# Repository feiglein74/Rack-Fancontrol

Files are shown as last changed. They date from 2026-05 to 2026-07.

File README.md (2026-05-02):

# Rack-Fancontrol

Eine bewusst überdimensionierte Lüftersteuerung für ein Mini-Serverrack.

Ein **ESP32-S3** läuft mit ESPHome-Firmware, holt sich live die CPU-
und SFP+-DDM-Temperaturen eines **MikroTik CRS305** per SNMP, schickt
sie durch einen PID-Regler und steuert damit zwei 12-V-Lüfter mit
einer gestaffelten Kühlkurve: Der leise 4-Pin-Lüfter macht die
Grundlast, der laute 2-Pin-Lüfter wird erst zugeschaltet, wenn ein
Lüfter allein nicht mehr reicht.

Ziel: Rack kühl halten, Büro leise halten — und dabei etwas zum
Drucken, Löten und Tunen haben.

---

## Hardware

| Bauteil | Funktion |
|---|---|
| ESP32-S3-DevKitC-1 | Hirn. Läuft ESPHome 2026.3.x auf `esp-idf`. |
| 4-Pin-PC-Lüfter (12 V) | Hauptlüfter. PWM @ 25 kHz auf GPIO4, Tacho auf GPIO5. |
| 2-Pin-BLDC-Lüfter (12 V) | Boost-Lüfter. Über 60N03-MOSFET-Modul @ 100 Hz auf GPIO6. |
| INA219 (0,1 Ω Shunt) | Live-Strom-/Leistungsmessung der Lüfterschiene. |
| XW026FR4 Buck Converter | 12 V → 5 V für den ESP. |
| BSS138 Levelshifter | 3,3 V ↔ 5 V auf den PWM-/Tacho-Leitungen für den 4-Pin-Lüfter. |
| 3× WAGO 221-415 | Lötfreie Klemmen für 12 V / 12 V-nach-INA / GND. |

I²C läuft mit **100 kHz** (das billige INA219-Breakout antwortet bei
den 50 kHz Default nicht). Lüfter 2 PWM läuft mit **100 Hz**, weil
2-Pin-BLDC-Lüfter sich bei 25 kHz Versorgungschoppen nicht regeln
lassen — sie schalten dann nur an/aus durch. Bei niedriger PWM-
Frequenz mittelt die Motor-Induktivität die Pulse weg.

## Regelarchitektur

```
MikroTik SNMP (CPU + SFP+1/2 Temperaturen, 60 s Poll, EMA-gefiltert)
                         │
                         ▼
                  rack_max_temp (Template-Maximum)
                         │
                         ▼
                  climate.pid (45 °C Sollwert, ±1,5 °C Totband)
                         │ cool_output (0,0..1,0)
                         ▼
                  Staged-Cooling Template-Output
                ┌────────┴────────┐
                ▼                 ▼
        Lüfter 1 (0..0,5)  Lüfter 2 (0,5..1,0)
        4-Pin LEDC PWM     2-Pin via MOSFET
```

Die `fan.speed`-Entities umschließen zusätzlich jeden LEDC-Output —
wenn `climate.mode = OFF` werden die Lüfter manuell aus Home Assistant
oder dem lokalen Web-UI steuerbar, ohne dass der PID-Regler dazwischen-
funkt.

## Features

- **PID über SNMP** — der Regler arbeitet gegen einen selbst-
  geschriebenen SNMPv2c-GET-Client (`components/snmp_sensor/`,
  ~250 Zeilen C++, ohne externe Library — nur ein ASN.1/BER-Encoder,
  ein Wert-Parser für INTEGER + Gauge32 und ein nicht-blockierender
  UDP-State-Machine).
- **Gestaffelte Kühlung** — ein einzelner PID-Output wird nicht-linear
  auf zwei Lüfter aufgeteilt, damit der Laute aus bleibt, solange es
  geht.
- **Auto-Kalibrierung** — ein Button "Fan 1 kalibrieren" fährt die
  PWM-Pegel 0/25/40/55/70/85/100 % ab und interpoliert die Totzonen-
  Schwelle aus der Tacho-Antwort. Der PID-Output wird anschließend
  auf `[Totzone..100 %]` skaliert, damit der Lüfter nie in seinem
  trägen Bereich hängt.
- **Live-Tuning** — `climate.pid.set_control_parameters` und
  `climate.pid.autotune` sind als Service exponiert; kein Reflash
  nötig.
- **Lokale INA219-Telemetrie** — Strom, Spannung und Leistung der
  Lüfterschiene mit 1 Hz.
- **Home-Assistant-nativ** — Climate-, Fan-, Sensor- und
  Text-Entities über die ESPHome-API; OTA auf Port 3232,
  Web-UI auf Port 80.

## Build & Flash

ESPHome 2026.3.x ist Voraussetzung. WLAN-Zugangsdaten liegen in
`secrets.yaml` (gitignored — selbst anlegen mit `wifi_ssid` /
`wifi_password`).

```bash
esphome config   rack-fancontrol.yaml                   # validieren
esphome compile  rack-fancontrol.yaml                   # bauen
esphome run      --device <ip|serial> rack-fancontrol.yaml
esphome logs     --device <ip> rack-fancontrol.yaml
```

Erstflash über USB-C, danach geht alles per OTA. Innerhalb 60 s
nach einem OTA das Gerät **nicht** stromlos machen — sonst rollt
`safe_mode` das Image als vermeintlicher Boot-Loop wieder zurück.

## Repo-Struktur

```
rack-fancontrol.yaml          ESPHome-Hauptkonfiguration
components/snmp_sensor/       Eigene external_component (SNMPv2c-GET-Client)
enclosure/                    OpenSCAD-Quellen für das 3D-Druck-Gehäuse
CLAUDE.md                     Engineering-Notizen, Pin-Map, Begründungen
```

## Gehäuse (work in progress)

Die Steuerung wandert gerade vom Dupont-Kabel-Dschungel in ein
parametrisches 3D-Druck-Gehäuse, entworfen in **OpenSCAD** für
FDM-Druck.

**Aktueller Stand — Bodenplatte (`enclosure/base_plate.scad`):**

- 160 × 90 × 3 mm abgerundetes Rechteck, mit Lüftungsschlitzen
  unter den warmen Modulen (ESP, MOSFET) für passive Konvektion.
- **Snap-Cradles** für jedes Modul — keine Schrauben. Vier
  gedruckte Federclips pro Modul greifen mit 0,8 mm Lippe über
  die PCB-Kante; die Platinen werden von oben eingeklippst.
- Das ESP-DevKit ist **kopfüber** montiert (Pin-Header oben,
  damit Dupont-Stecker direkt von oben aufgesteckt werden können)
  auf 8 mm Standoffs, damit die WiFi-Antenne und die Unterseiten-
  Bauteile Platz haben.
- WAGO-221-415-Halter nutzen ein Community-STL
  ([Wago 221-415 Connector x 5 Mount](https://www.printables.com/model/321904)
  von *Wiseone*), importiert und im parametrischen Layout neu
  positioniert.
- Alle Modul-Maße sind erst mal Typenwerte; nach dem ersten
  Testdruck werden sie pro echtem Bauteil mit Messschieber
  feingetrimmt.

**Geplant:**

- Wände + Deckel (zum Aufstecken), mit Kabelausgängen auf den
  schmalen Seiten (12 V rein, Lüfteranschlüsse raus, USB-C-
  Wartungsklappe).
- Entweder Rack-Format (10″) als Frontblende oder freistehend —
  je nachdem, ob im LabRax noch ein Slot frei wird.
- Eine kleine Frontaussparung für ein OLED-Statusdisplay liegt
  noch auf dem Tisch.

Die OpenSCAD-Quelle ist absichtlich parameterlastig: Modul tauschen
(anderes INA-Breakout, kleinerer Buck etc.) ist eine Zeile Edit
plus Re-Render.

## Bekannte Eigenheiten

- **Lüfter-2-Brumm.** 100 Hz PWM hört man. Ein 47–100 µF Elko
  parallel zum Lüfter glättet das fast komplett weg — silent
  upgrade, noch nicht eingebaut.
- **MikroTik-Temperaturauflösung.** RouterOS meldet die CPU-
  Temperatur nur in ganzen Grad (die deciDegree-OID-Codierung
  ist kosmetisch). Der EMA-Filter (α=0,4, 60 s Poll) glättet
  die Quantisierungsstufen, damit der D-Term des PID die
  Integer-Sprünge nicht als Schläge sieht.
- **SFP+-DDM.** Modultemperaturen kommen als Gauge32 über SNMP.
  Der Custom-Parser musste auf Tag `0x42` erweitert werden, weil
  die ursprüngliche INTEGER-only-Version NaN zurückgab. Das
  Modul `sfpplus4-uplink` ist aus dem PID-Input ausgenommen —
  dessen DDM-Werte schwanken zu stark.
- **VLAN-Routing nötig.** Der ESP hängt im IoT-VLAN, der MikroTik
  im Management-VLAN. UDP/161 muss zwischen beiden geöffnet sein.

## Lizenz

Privates Hobbyprojekt; veröffentlicht, falls jemand etwas davon
brauchen kann. Keine Garantie — das Ding pustet glücklich Lüfter
in einem Schrank, kein Rechenzentrum dahinter.

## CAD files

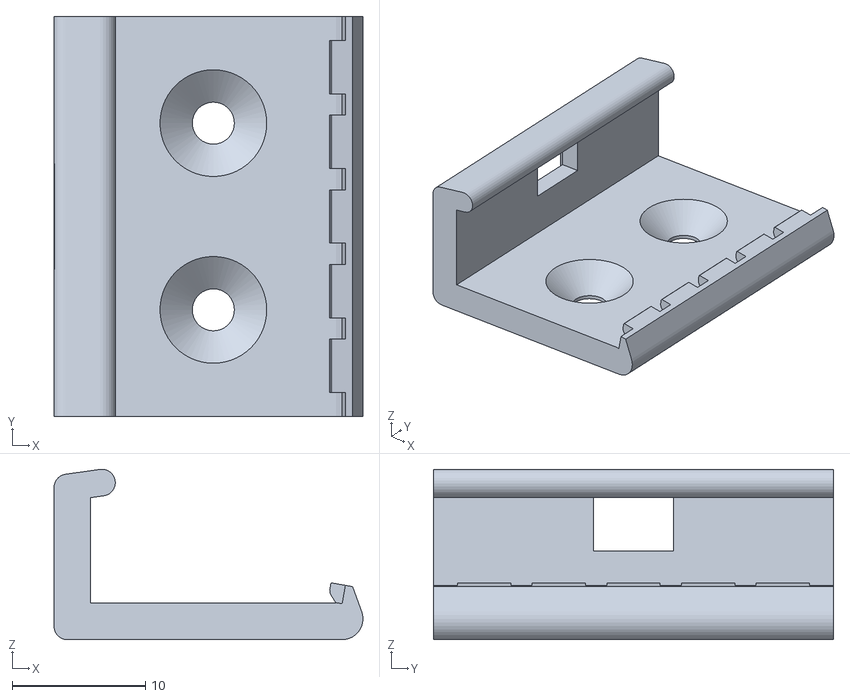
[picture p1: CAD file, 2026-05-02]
enclosure/wago221_x1.stl
23.2 x 30.0 x 12.8

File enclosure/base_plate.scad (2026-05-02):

// rack-fancontrol enclosure — base plate with module snap-cradles.
// Parametric. All dimensions in mm.
// Print FDM, 0.2 mm layers, 3 perimeters, 20 % infill.
//
// After first test print, fine-tune per-module dimensions with calipers
// against the real modules and re-render.

$fn = 48;

// ========== tolerances ==========
slop       = 0.3;   // extra clearance around PCB footprint
clip_over  = 0.8;   // how far the clip lip overhangs the PCB top

// ========== plate ==========
plate_thick = 3;
plate_l     = 160;  // X  -- short sides host the cable entries
plate_w     = 90;   // Y
corner_r    = 3;

// ========== typical module dimensions ==========
// [length, width, height, pcb_thick]  (height = tallest component on PCB)
esp_dim    = [70, 26, 20, 1.6];   // ESP32-S3 DevKitC-1 (USB-C + header)
ina_dim    = [22, 17,  8, 1.6];   // GY-219 breakout
buck_dim   = [30, 20, 12, 1.6];   // XW026FR4
mosfet_dim = [35, 22, 12, 1.6];   // 60N03 module
shift_dim  = [25, 20,  6, 1.6];   // BSS138 4-ch level shifter

// The ESP DevKit is mounted FLIPPED (pin headers facing up so you can
// plug Dupont wires in directly from above). That requires extra
// clearance under the PCB for the chip + WiFi-antenna + bottom-side
// components -- typical DevKitC-1 is ~4 mm tall on the chip side, so
// 8 mm standoff gives margin. USB-C end points towards the enclosure's
// left short side (x=0) so the programming cable exits cleanly.
esp_standoff = 8;
default_standoff = 1.5;

// WAGO 221-415 holder -- using community STL (Printables "Wago 221-415
// Connector x 5 Mount" by Wiseone, 1x variant downloaded as wago221_x1.stl).
// Bounding box of the STL: X 23.2, Y 30.0, Z 12.8.  STL origin has the
// long axis along Y (negative) and a small tab hanging at negative X.
wago_stl_size   = [23.2, 30.0, 12.8];
wago_stl_offset = [-2.75, -30.0, -2.75];  // min-corner offset in STL frame
wago_count      = 3;
wago_gap        = 3;

// ========== module positions ==========
// Layout (X = 0 at left, Y = 0 at bottom, both in "plate" frame):
//   Bottom row  — WAGOs (cable clamps / terminal strip)
//   Middle row  — Buck, Level-Shifter, INA
//   Top row     — ESP32-S3, MOSFET module
//
// Change these to move things around; snap_cradle() consumes them.

wago_y = 6;
esp_pos   = [  8, 55];
mosfet_pos= [ 90, 58];
buck_pos  = [  6, 32];
shift_pos = [ 45, 33];
ina_pos   = [ 80, 34];

// ========== primitives ==========

// rounded rectangular base
module plate() {
    linear_extrude(plate_thick)
    offset(r = corner_r) offset(delta = -corner_r)
        square([plate_l, plate_w], center = false);
}

// A single snap clip standing on the plate top at (x,y) with the
// retaining lip facing in direction `dir` (unit vector, inward towards
// the PCB center).  Clips are printed vertically, no supports.
module snap_clip(pcb_thick) {
    pillar_w = 4;          // along PCB edge
    pillar_t = 2;          // perpendicular to PCB edge
    lip_h    = 1.2;
    pillar_h = pcb_thick + lip_h + 0.4;

    // body pillar
    cube([pillar_w, pillar_t, pillar_h]);
    // inward-facing lip: sloped triangular prism so PCB slides past it
    translate([0, pillar_t, pillar_h - lip_h])
        rotate([90, 0, 0])
        linear_extrude(pillar_t + clip_over)
        polygon([[0, 0], [pillar_w, 0], [pillar_w, lip_h], [0, lip_h]]);
}

// Four snap clips at corners of a module footprint, plus standoff pads
// in the corners so the PCB doesn't scrape the plate.  `standoff_h`
// sets the PCB's top surface above the plate; the snap clips grow to
// match so the lip still catches the PCB edge.
module snap_cradle(pos, dim, standoff_h = default_standoff) {
    l = dim[0]; w = dim[1]; pcb_t = dim[3];
    translate([pos[0], pos[1], plate_thick]) {
        // 4 standoff columns at the PCB corners (form the cradle floor)
        for (sx = [3, l - 3], sy = [3, w - 3])
            translate([sx, sy, 0])
                cylinder(h = standoff_h, d = 4);

        // 4 snap clips at the PCB edges
        translate([0, 0, standoff_h]) {
            translate([-2, -2, 0]) snap_clip(pcb_t);
            translate([l + 2, -2, 0])
                mirror([1, 0, 0]) snap_clip(pcb_t);
            translate([-2, w + 2, 0])
                mirror([0, 1, 0]) snap_clip(pcb_t);
            translate([l + 2, w + 2, 0])
                mirror([0, 1, 0]) mirror([1, 0, 0]) snap_clip(pcb_t);
        }
    }
}

// WAGO 221 holder: imports community STL, re-anchors so the STL's
// min-corner sits at (pos, plate_thick) on our plate.
module wago_holder(pos) {
    translate([pos[0] - wago_stl_offset[0],
               pos[1] - wago_stl_offset[1],
               plate_thick - wago_stl_offset[2]])
        import("wago221_x1.stl", convexity = 5);
}

// ========== assembly ==========

module base_plate() {
    difference() {
        union() {
            plate();

            // module snap-cradles
            snap_cradle(esp_pos,    esp_dim,    esp_standoff);
            snap_cradle(mosfet_pos, mosfet_dim);
            snap_cradle(buck_pos,   buck_dim);
            snap_cradle(shift_pos,  shift_dim);
            snap_cradle(ina_pos,    ina_dim);

            // WAGO row -- 3x imported STL holders side by side
            for (i = [0 : wago_count - 1])
                wago_holder([ 10 + i * (wago_stl_size[0] + wago_gap), wago_y ]);
        }

        // ventilation slots under ESP + MOSFET for airflow inside the
        // future enclosure (cheap convection)
        for (x = [15, 30, 45, 100, 115, 130])
            translate([x, 40, -0.1])
                cube([3, 10, plate_thick + 0.2]);
    }
}

base_plate();

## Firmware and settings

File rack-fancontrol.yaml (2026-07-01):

esphome:
  name: rack-fancontrol
  friendly_name: Rack Fan Control
  platformio_options:
    board_build.flash_mode: dio
  on_boot:
    # Moderate baseline speed until the first SNMP reading arrives and the
    # PID takes over. 100% at boot cools the MikroTik too hard and causes
    # overshoot once climate.mode=COOL kicks in.
    - priority: -100
      then:
        - fan.turn_on:
            id: fan1
            speed: 50
        - fan.turn_on:
            id: fan2
            speed: 50

esp32:
  board: esp32-s3-devkitc-1
  variant: esp32s3
  framework:
    type: esp-idf

logger:
  level: DEBUG
  hardware_uart: UART0

api:

ota:
  - platform: esphome

web_server:
  version: 3
  port: 80

external_components:
  - source:
      type: local
      path: components

wifi:
  ssid: !secret wifi_ssid
  password: !secret wifi_password

i2c:
  sda: GPIO8
  scl: GPIO9
  scan: true
  frequency: 100kHz

debug:
  update_interval: 10s

globals:
  - id: fan1_deadzone_pwm
    type: float
    restore_value: true
    initial_value: '55.0'
  - id: fan1_max_rpm
    type: float
    restore_value: true
    initial_value: '2000.0'
  - id: calib_samples
    type: "float[6]"
    restore_value: false
    initial_value: '{0, 0, 0, 0, 0, 0}'
  - id: calib_min_rpm
    type: float
    restore_value: false
    initial_value: '0.0'
  - id: auto_cool_started
    type: bool
    restore_value: false
    initial_value: 'false'

button:
  - platform: template
    name: "Fan 1 kalibrieren"
    id: btn_calibrate_fan1
    on_press:
      then:
        - script.execute: calibrate_fan1

script:
  - id: calibrate_fan1
    mode: restart
    then:
      - logger.log: "=== Fan 1 Kalibrierung: START ==="
      - climate.control:
          id: rack_cooling
          mode: "OFF"
      - delay: 500ms
      # Baseline: PWM 0% -> fan idles at its natural minimum
      - fan.turn_off: fan1
      - delay: 8s
      - lambda: "id(calib_min_rpm) = id(fan1_tach).state;"
      - logger.log:
          format: "Min RPM (PWM off): %.0f"
          args: ["id(calib_min_rpm)"]
      # 6 Messpunkte: 25 / 40 / 55 / 70 / 85 / 100 % PWM, je ~6 s einschwingen
      - fan.turn_on: {id: fan1, speed: 25}
      - delay: 6s
      - lambda: "id(calib_samples)[0] = id(fan1_tach).state;"
      - fan.turn_on: {id: fan1, speed: 40}
      - delay: 6s
      - lambda: "id(calib_samples)[1] = id(fan1_tach).state;"
      - fan.turn_on: {id: fan1, speed: 55}
      - delay: 6s
      - lambda: "id(calib_samples)[2] = id(fan1_tach).state;"
      - fan.turn_on: {id: fan1, speed: 70}
      - delay: 6s
      - lambda: "id(calib_samples)[3] = id(fan1_tach).state;"
      - fan.turn_on: {id: fan1, speed: 85}
      - delay: 6s
      - lambda: "id(calib_samples)[4] = id(fan1_tach).state;"
      - fan.turn_on: {id: fan1, speed: 100}
      - delay: 6s
      - lambda: "id(calib_samples)[5] = id(fan1_tach).state;"
      - lambda: |-
          const int duties[6] = {25, 40, 55, 70, 85, 100};
          const float margin = 150.0f;  // RPM must exceed min+margin to count as "scaling"
          int idx = -1;
          for (int i = 0; i < 6; i++) {
            ESP_LOGI("calib", "  duty=%d%%  rpm=%.0f", duties[i], id(calib_samples)[i]);
            if (idx < 0 && id(calib_samples)[i] > id(calib_min_rpm) + margin) {
              idx = i;
            }
          }
          if (idx > 0) {
            // Interpolate between the last "still min" point and the first "scaling" point
            float d_low = (float) duties[idx - 1];
            float d_high = (float) duties[idx];
            float r_low = id(calib_samples)[idx - 1];
            float r_high = id(calib_samples)[idx];
            float target = id(calib_min_rpm) + margin;
            id(fan1_deadzone_pwm) = d_low + (target - r_low) * (d_high - d_low) / (r_high - r_low);
          } else if (idx == 0) {
            id(fan1_deadzone_pwm) = (float) duties[0];
          } else {
            // fan never scaled (broken?)  keep previous value
            ESP_LOGW("calib", "Fan did not exceed minimum at any tested duty; keeping previous threshold");
          }
          id(fan1_max_rpm) = id(calib_samples)[5];
          ESP_LOGI("calib", "=== RESULT: deadzone_pwm=%.1f%%  max_rpm=%.0f ===",
                   id(fan1_deadzone_pwm), id(fan1_max_rpm));
      - fan.turn_off: fan1
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

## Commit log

2026-05-02 Initial commit: ESP32-S3 mini-rack fan controller
    ESPHome firmware regulating two 12 V fans (one 4-pin PWM, one 2-pin
    via 60N03 MOSFET module) against the maximum of MikroTik CRS305 CPU
    temperature and SFP+ DDM module temperatures, pulled live over SNMPv2c.
    Custom external_component (components/snmp_sensor/) implements a
    single-OID SNMPv2c GET client over UDP with hand-rolled ASN.1/BER
    encoder and INTEGER/Gauge32 parser -- no external library dependency.
    Control path: SNMP -> EMA-filtered template max -> climate.pid ->
    staged template output -> two LEDC PWMs (25 kHz fan1, 100 Hz fan2).
    Includes initial parametric OpenSCAD enclosure base plate with snap
    cradles for ESP/INA219/buck/MOSFET/l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
    [base_plate.scad, wago221_x1.stl]
2026-05-02 Add README with project overview and enclosure roadmap
    GitHub-facing front page: hardware list, control architecture,
    build/flash instructions, repo layout, and the in-progress
    3D-printed enclosure with a description of the current base
    plate (parametric snap-cradle layout) and the planned walls/lid.
2026-07-01 Add SNMP failure failsafe, runtime IP config, and status indicator
    Previously an SNMP outage (e.g. the CRS305's DHCP address changing) went
    unnoticed: the snmp_sensor stops publishing on timeout, so the temperature
    froze on its last value and the PID kept regulating on a phantom reading --
    eventually coasting the fans down to near zero while the rack could overheat,
    with nothing signalling the fault.
    - timeout filter (180s) on all SNMP sensors -> publish NaN instead of freezing
    on the last value; sensors go "unavailable" in HA on outage.
    - 50% failsafe: interval watchdog forces both fans to a fixed 50% floor while
    rack_max_temp is NaN and climate != OFF; fan_group_output skips PID write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
    [rack-fancontrol.yaml]
